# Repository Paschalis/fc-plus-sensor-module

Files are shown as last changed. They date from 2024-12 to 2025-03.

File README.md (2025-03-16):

# FC Plus Sensor Module
<p align="center">
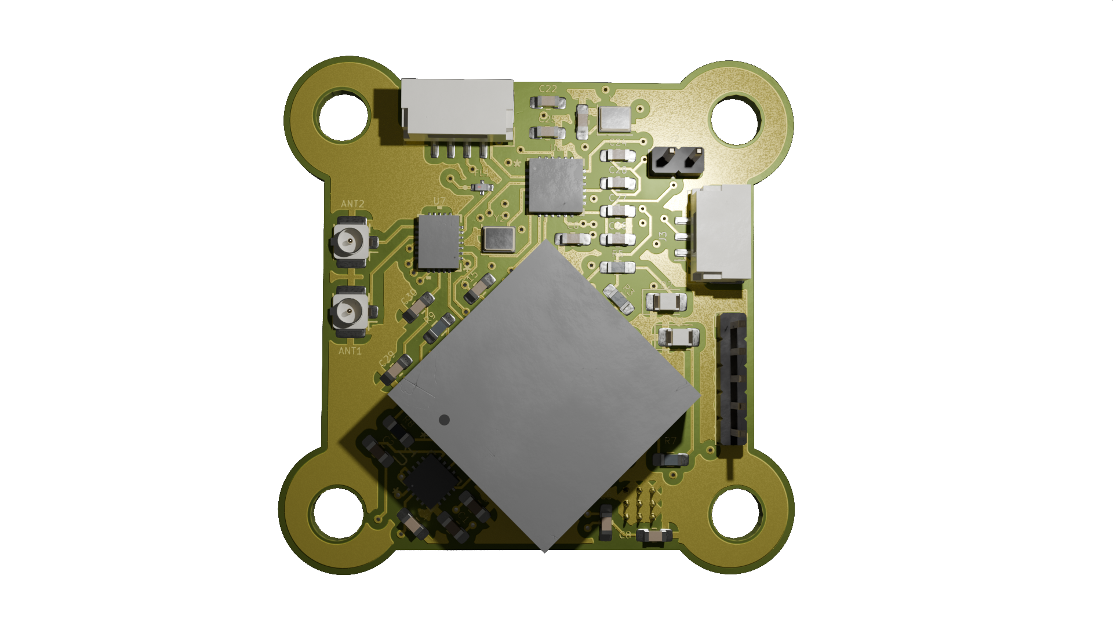
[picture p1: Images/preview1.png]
preview1
  
</p>
<p align="center">
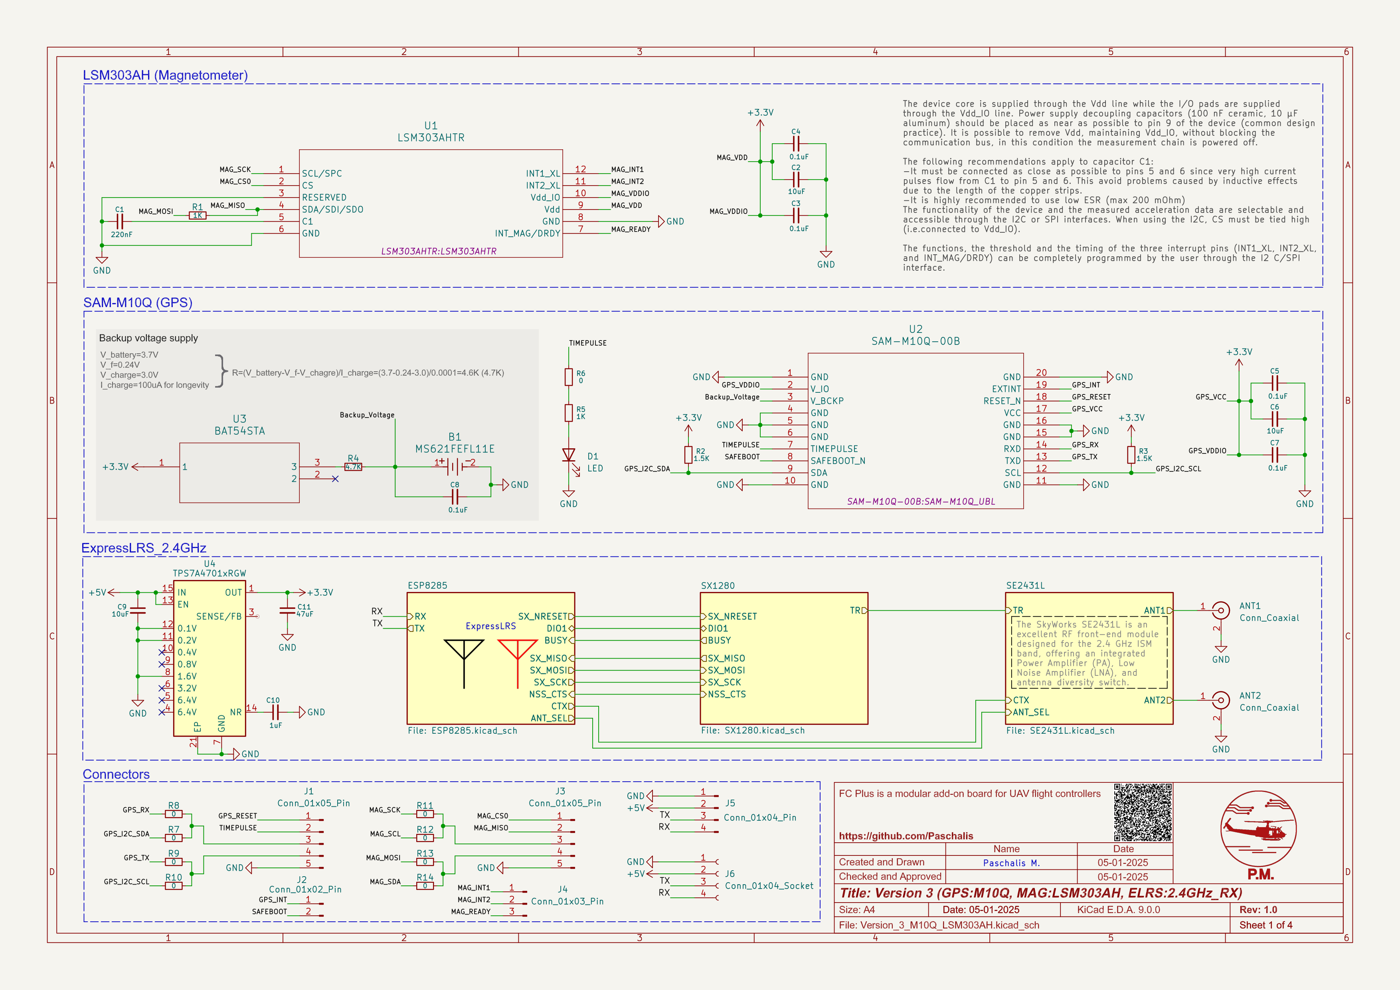
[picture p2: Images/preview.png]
preview
  
</p>

**FC Plus** is a modular add-on board designed for UAV flight controllers, providing advanced telemetry, GPS, object avoidance (ToF, Sonar, IR), and LED indicators for status feedback. This repository contains the necessary documentation, hardware setup guides, sensor integration instructions, and communication protocols (LoRa/WiFi) to enhance UAV autonomy and safety.

# Board Designs Overview

This repository contains a collection of **FC Plus Sensor Modules Boards** categorized by their transmission modes. More details about the transmission modes can be found in the [Transmission Modes Classification](SensorFCPlus/README.md).

> **Note:** The PCB colors are used to visually distinguish the boards. The **Antenna Diversity** boards feature **yellow** PCBs, while the **True Diversity** boards are **blue**. The **Gemini Mode** boards are marked with **red** PCBs, and the **Gemini Xrossband (GemX)** boards are designed with **purple** PCBs for easy identification.

<p align="center">
    <a href="https://paschalis.github.io/fc-plus-sensor-module/" target="_blank">
        
    </a>
</p>

## 1. Antenna Diversity Boards (Yellow Boards)

### FC Plus Sensor Modules Boards at 2.4GHz

| Name | Features | Preview |
|---|---|---|
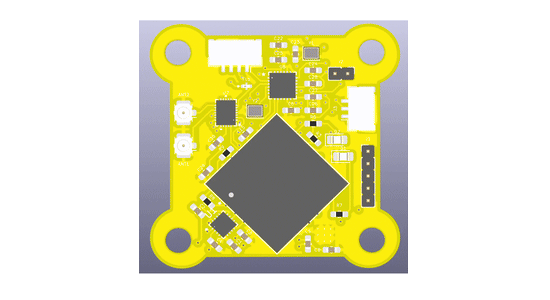
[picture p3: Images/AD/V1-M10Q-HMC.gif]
| V1-M10Q-HMC | GPS: SAM-M10Q, MAG: HMC5883L, ELRS: 2.4GHz RX |  <p align="center"> Click on the image to view the files </p>|
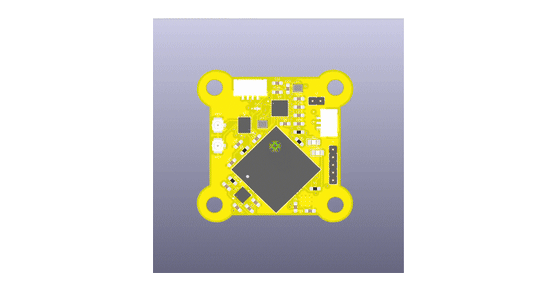
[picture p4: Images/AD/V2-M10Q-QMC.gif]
| V2-M10Q-QMC | GPS: SAM-M10Q, MAG: QMC5883L, ELRS: 2.4GHz RX |  <p align="center"> Click on the image to view the files </p>|
| V3-M10Q-LSM | GPS: SAM-M10Q, MAG: LSM303AH, ELRS: 2.4GHz RX | Preview <p align="center"> Click on the image to view the files </p> |

### FC Plus Sensor Modules Boards at 900MHz

<details>
<summary>Click to view Antenna Diversity Boards at 900MHz</summary>

| Name | Features | Preview |
|---|---|---|
| V1-M10Q-HMC | GPS: SAM-M10Q, MAG: HMC5883L, ELRS: 900MHz RX |  |
| V2-M10Q-QMC | GPS: SAM-M10Q, MAG: QMC5883L, ELRS: 900MHz RX |  |
| V3-M10Q-LSM | GPS: SAM-M10Q, MAG: LSM303AH, ELRS: 900MHz RX |  |

</details>

---
> **Note:** In the following boards, the **LSM303AH** magnetometer was selected over other options due to its **better overall performance**, offering improved accuracy and reliability in magnetic field sensing. The **MAX-M10S** GPS module was chosen instead of the SAM-M10Q for its **lower cost** while still providing good performance for navigation, making it a more economical choice for the boards.

## 2. True Diversity Boards (Blue Boards)

### FC Plus Sensor Modules Boards at 2.4GHz
| Name | Features | Preview |
|---|---|---|
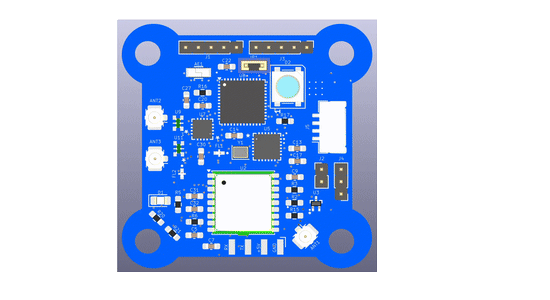
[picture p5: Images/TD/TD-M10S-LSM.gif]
| TD-M10S-LSM | GPS: MAX-M10S, MAG: LSM303AH, ELRS: 2.4GHz RX |  <p align="center"> Click on the image to view the files </p>|

### FC Plus Sensor Modules Boards at 900MHz
<details>
<summary>Click to view True Diversity Boards at 900MHz</summary>

| Name | Features | Preview |
|---|---|---|
| TD-M10S-LSM | GPS: MAX-M10S, MAG: LSM303AH, ELRS: 900MHz RX |  |

</details>

## 3. Gemini Mode Boards

> **Note:**  
> - The **Gemini boards** are actually the **True Diversity boards** operating in **Gemini Mode**.  
> - To enable **Gemini Mode**, set the **RX Antenna Mode** to **Gemini** via Lua script.  
> - **Single Antenna RX boards** can also operate in Gemini Mode but must use **Model 5** in **Model Config Matching** via Lua script.  
> - **Gemini-capable receivers** should use **Model 6** in **Model Config Matching**.  
> - Click on [🔗 **Go to True Diversity Full Diversity Boards (Blue Boards)**](#2-true-diversity-boards-blue-boards) to view compatible receivers.  
>  
> 📖 **Reference:** [ExpressLRS Gemini Mode Documentation](https://www.expresslrs.org/software/gemini/#what-is-gemini)  

## 4. Gemini Xrossband (GemX) Boards (Purple Boards)

### FC Plus Sensor Modules Boards
| Name | Features | Preview |
|---|---|---|
| GemX-M10S-LSM | GPS: MAX-M10S, MAG: LSM303AH, ELRS: 2.4GHz and 900MHz RX |  |

## Related Projects

### **Autonomous UAVs: MAVLink Communication Between FCs and SBCs**
This repository explores MAVLink communication between flight controllers and SBCs, enabling UAV autonomy with features like peripheral integration and real-time image processing.

<div align="center">

             
  

</div>

Explore more about the **MAVLink Communication Between FCs and SBCs** project and its integration into autonomous UAVs by clicking on the badge above to access the full documentation and setup guide.

### **Custom RX/TX Board Designs for GCS Communication**


This repository provides a receiver and transmitter solution for Ground Control Stations (GCS), designed to provide reliable telemetry and control using ELRS, mLRS, and MAVLink protocols. Featuring board designs optimized for long-range communication, minimal latency, and robust performance under varying conditions, these boards cater to diverse operational needs for UAV telemetry systems.

<div align="center">

                              
  

</div>

Explore the **Custom RX/TX Board Designs for GCS Communication** project and its integration into UAV telemetry systems by clicking on the badge above.

## Contributing

Your contributions and suggestions are crucial for the improvement of this project!  Feel free to submit pull requests or open issues if you encounter any problems.

## License

This project is licensed under the [GPLv3 License](https://opensource.org/licenses/GPL-3.0) - see the [LICENSE](LICENSE) file for details.

---

**Thank you for visiting fc-plus-sensor-module!**

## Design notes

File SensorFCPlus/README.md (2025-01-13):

# Transmission Modes Classification

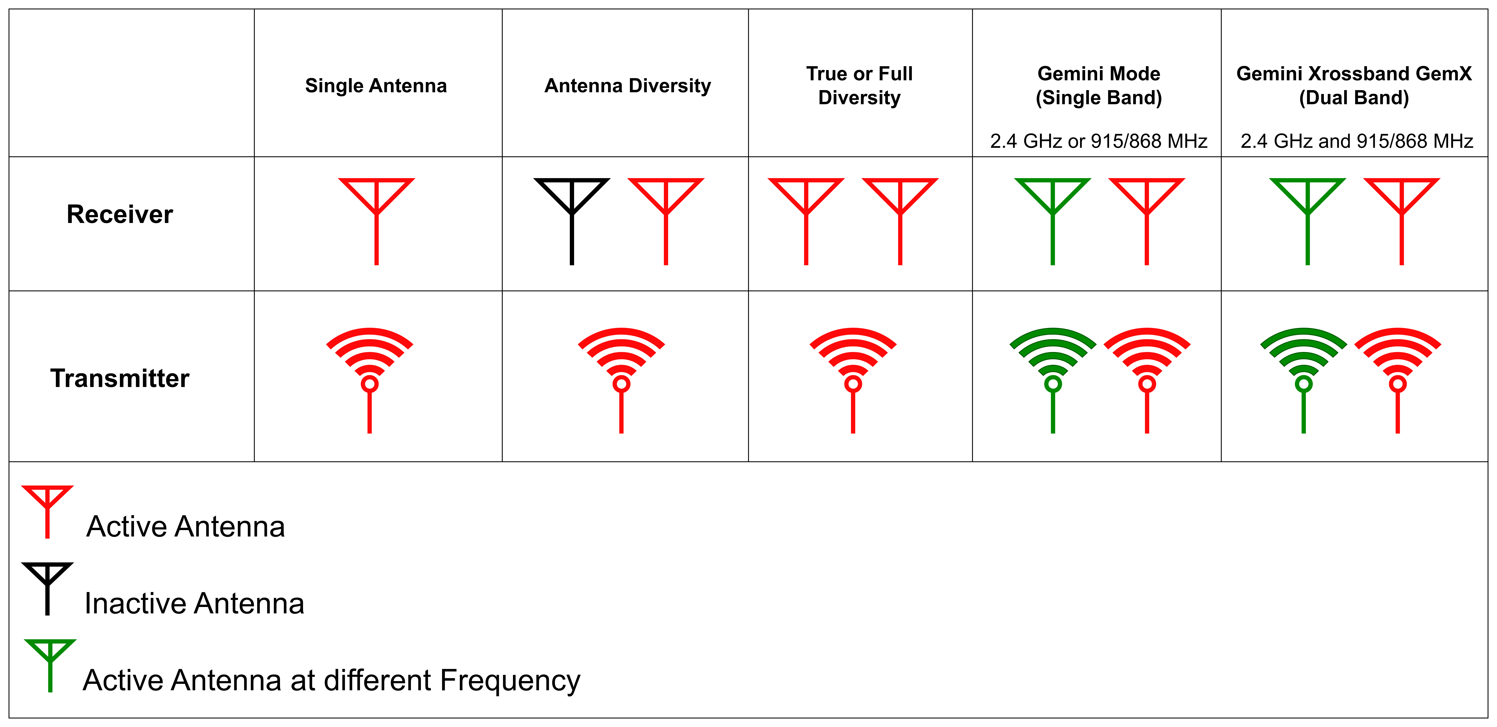
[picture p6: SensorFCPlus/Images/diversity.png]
Gemini Info


This document describes various transmission modes used in long-range LoRa (Long Range) wireless communication for drones. These modes leverage LoRa's unique capabilities to improve Signal Quality (LQ), mitigate interference, and enhance reliability over extended distances, making them ideal for drone applications in diverse environments.
## Transmission Modes

### 1. Single Antenna
- **Description**:  
  Uses one antenna on both the transmitter and receiver, operating over a single frequency channel.
- **Advantages**:  
  - Simplicity  
  - Low cost  
- **Limitations**:  
  - Highly susceptible to interference and signal loss.  

### 2. Antenna Diversity

- **Description**:  
  The receiver employs two antennas to select the best signal, while the transmitter uses a single antenna. Communication occurs over a single frequency channel.  
- **Advantages**:  
  - Improved signal quality due to antenna selection.  
- **Limitations**:  
  - Only one frequency channel is used.  
  - Transmission lacks diversity.  

### 3. True Diversity or Full Diversity
- **Description**:  
  Both the transmitter and receiver utilize two independent Semtech LoRa chips, each connected to its own antenna, operating on the same frequency. This setup provides full diversity for both transmitting and receiving.  
- **Advantages**:  
  - Enhanced signal quality through full transmitter and receiver diversity.  
  - Redundancy in signal transmission and reception.  
- **Limitations**:  
  - Increased complexity and cost.  

### 4. Gemini Mode (Single Band)
- **Description**:  
  The transmitter sends packets on two frequencies within the same band (e.g., 2.4 GHz or 900 MHz), spaced approximately 40 MHz apart for 2.4 GHz and 10 MHz apart for 900 MHz. A true diversity receiver with two antennas and LoRa chips receives both signals simultaneously.  
- **Advantages**:  
  - Superior interference mitigation by utilizing two frequencies within the same band.  
  - Improved stability and reliability of signal quality.  
- **Limitations**:  
  - Limited to a single frequency band.  

### 5. Gemini Xrossband GemX (Dual Band)
- **Description**:  
  The transmitter operates simultaneously on two different frequency bands (e.g., 2.4 GHz and 900 MHz), each managed by independent LoRa chips. The receiver employs true diversity hardware with two antennas and LoRa chips operating on distinct bands.  
- **Advantages**:  
  - Enhanced interference avoidance by operating across separate bands.  
  - Increased performance and redundancy for long-range communication.  
- **Limitations**:  
  - More complex and expensive hardware due to dual-band operation.  

---

## Transmission Mode Classification Chart

| Mode | Frequency Channels | Antennas (TX) | Antennas (RX)| Interference Mitigation | Signal Quality  | Receiver Type |
|---|---|---|---|---|---|---|
| **Single Antenna** | 1 | 1 | 1 | Low | Low | Simple Receiver |
| **Antenna Diversity** | 1 | 1 | 2 | Moderate | Moderate | Diversity Receiver |
| **True Diversity or Full Diversity**  | 1 | 1 | 2 | High | High | Diversity Receiver |
| **Gemini Mode (Single Band)**| 2 (within 1 band) | 2 | 2 | Very High | Very High | Diversity Receiver |
| **Gemini Xrossband GemX (Dual Band)** | 2 (across 2 bands) | 2 | 2 | Excellent | Excellent | Dual-band Receiver |

---

## Summary

This classification illustrates the progression from basic single antenna setups to advanced true diversity and dual-band configurations:

- **Single Antenna** and **Antenna Diversity** provide fundamental solutions suitable for simple environments.  
- **True Diversity** or **Full Diversity** and **Gemini Mode (Single Band)** offer significant enhancements in reliability and interference mitigation within the same band.  
- **Gemini Xrossband GemX (Dual Band)** delivers optimal performance by leveraging dual-band communication, ideal for complex and interference-prone environments.  

Understanding these modes enables the selection of appropriate communication systems tailored to specific drone operation requirements, ensuring robust and efficient wireless links.

---

## References

- [mLRS GitHub Repository](https://github.com/olliw42/mLRS)  
- [mLRS Documentation](https://github.com/olliw42/mLRS-docu)  
- [mLRS Hardware Repository](https://github.com/olliw42/mLRS-hardware/tree/master)  
- [ArduPilot: mLRS RC Overview](https://ardupilot.org/copter/docs/common-mlrs-rc.html)  
- [ExpressLRS: Gemini Overview](https://www.expresslrs.org/software/gemini/)  
- [ExpressLRS Documentation](https://www.expresslrs.org/)  

[⬅️ Go Back to Main README](../README.md)

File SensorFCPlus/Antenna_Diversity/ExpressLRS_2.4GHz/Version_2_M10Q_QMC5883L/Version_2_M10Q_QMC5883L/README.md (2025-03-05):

<div align="center">

# V2-M10Q-QMC

Antenna Diversity 
(GPS: SAM-M10Q, MAG: QMC5883L, ELRS:2.4GHz_RX)

</div>

Board Preview
## Bill of Materials

| Reference | Value | Datasheet | Footprint | Qty | DNP |
|---|---|---|---|-----|-----|
| AE1 | Antenna | ~ | RF_Antenna:Texas_SWRA117D_2.4GHz_Right | 1 | |
| ANT1, ANT2 | Conn_Coaxial | ~ | Connector_Coaxial:U.FL_Hirose_U.FL-R-SMT-1_Vertical | 2 | |
| B1 | MS621FEFL11E | MS621FEFL11E | MS621FE-FL11E:MS621FE-FL11E | 1 | |
| C1, C4, C6, C12, C13, C15 | 0.1uF | ~ | Capacitor_SMD:C_0805_2012Metric_Pad1.18x1.45mm_HandSolder | 6 | |
| C2 | 0.22uF | ~ | Capacitor_SMD:C_0805_2012Metric_Pad1.18x1.45mm_HandSolder | 1 | |
| C3 | 4.7uF | ~ | Capacitor_SMD:C_0805_2012Metric_Pad1.18x1.45mm_HandSolder | 1 | |
| C5, C7, C14, C21 | 10uF | ~ | Capacitor_SMD:C_0805_2012Metric_Pad1.18x1.45mm_HandSolder, ECASD40J106M055K00:ECASD40J106M055K00 | 4 | |
| C8 | 1uF | ~ | Capacitor_SMD:C_0805_2012Metric_Pad1.18x1.45mm_HandSolder | 1 | |
| C9 | 47uF | ~ | Capacitor_SMD:C_0805_2012Metric_Pad1.18x1.45mm_HandSolder | 1 | |
| C10, C11, C16, C17, C18, C19, C20, C24, C28, C32 | 100nF | ~ | Capacitor_SMD:C_0805_2012Metric_Pad1.18x1.45mm_HandSolder | 10  | |
| C22, C23, C30, C31 | 10pF | ~ | Capacitor_SMD:C_0805_2012Metric_Pad1.18x1.45mm_HandSolder | 4 | |
| C25, C26 | 10nF | ~ | Capacitor_SMD:C_0805_2012Metric_Pad1.18x1.45mm_HandSolder | 2 | |
| C27 | 470nF | ~ | Capacitor_SMD:C_0805_2012Metric_Pad1.18x1.45mm_HandSolder | 1 | |
| C29 | 2.2uF | ~ | Capacitor_SMD:C_0805_2012Metric_Pad1.18x1.45mm_HandSolder | 1 | |
| D1, D2 | LED | ~ | LED_SMD:LED_0805_2012Metric_Pad1.15x1.40mm_HandSolder | 2 | |
| FL1 | 2450FM07D0034T | [Datasheet](https://www.mouser.co.uk/datasheet/2/611/2450FM07D0034-1375634.pdf) | 2450FM07D0034T:2450FM07D0034T | 1 | |
| J1 | Conn_01x05_Pin | ~ | Connector_PinHeader_2.00mm:PinHeader_1x05_P2.00mm_Vertical | 1 | |
| J2 | Conn_01x02_Pin | ~ | Connector_PinHeader_2.00mm:PinHeader_1x02_P2.00mm_Vertical | 1 | |
| J3 | Conn_01x03_Socket | ~ | Connector_JST:JST_GH_SM03B-GHS-TB_1x03-1MP_P1.25mm_Horizontal | 1 | |
| J5 | Conn_01x04_Pin | ~ | Connector_JST:JST_GH_SM04B-GHS-TB_1x04-1MP_P1.25mm_Horizontal | 1 | |
| J6 | Conn_01x04_Socket | ~ | Connector_Harwin:Harwin_M20-89004xx_1x04_P2.54mm_Horizontal | 1 | |
| JP1 | Jumper_2_Bridged | ~ | Jumper:SolderJumper-2_P1.3mm_Open_RoundedPad1.0x1.5mm | 1 | |
| R1, R2, R8, R9 | 1.5K | ~ | Resistor_SMD:R_0805_2012Metric_Pad1.20x1.40mm_HandSolder | 4 | |
| R3, R6, R18, R19, R20, R21, R23, R25 | 0 | ~ | Resistor_SMD:R_0603_1608Metric_Pad0.98x0.95mm_HandSolder, Resistor_SMD:R_0805_2012Metric_Pad1.20x1.40mm_HandSolder | 8 | |
| R4 | 4.7K | ~ | Resistor_SMD:R_0805_2012Metric_Pad1.20x1.40mm_HandSolder | 1 | |
| R5, R7 | 1K | ~ | Resistor_SMD:R_0805_2012Metric_Pad1.20x1.40mm_HandSolder | 2 | |
| R10, R11, R12, R13, R17 | 10K | ~ | Resistor_SMD:R_0805_2012Metric_Pad1.20x1.40mm_HandSolder | 5 | |
| R14 | 12K | ~ | Resistor_SMD:R_0805_2012Metric_Pad1.20x1.40mm_HandSolder | 1 | |
| R15 | 2.2K | ~ | Resistor_SMD:R_0805_2012Metric_Pad1.20x1.40mm_HandSolder | 1 | |
| R16 | 1.2K | ~ | Resistor_SMD:R_0805_2012Metric_Pad1.20x1.40mm_HandSolder | 1 | |
| U1 | QMC5883L | QMC5883L | QMC5883L:QMC5883L_QST | 1 | |
| U2 | SAM-M10Q-00B | SAM-M10Q-00B | SAM-M10Q-00B:SAM-M10Q_UBL | 1 | |
| U3 | BAT54STA | BAT54STA | BAT54STA:BAT54STA | 1 | |
| U4 | TPS7A4701xRGW | [Datasheet](https://www.ti.com/lit/ds/symlink/tps7a47.pdf) | Package_DFN_QFN:Texas_RGW0020A_VQFN-20-1EP_5x5mm_P0.65mm_EP3.15x3.15mm_ThermalVias | 1 | |
| U5 | ESP8285H16 | ESP8285H16 | ESP8285H16:QFN32_5X5_EXP | 1 | |
| U6 | SX1280IMLTRT | SX1280IMLTRT | SX1280IMLTRT:QFN24_4X4_SEM | 1 | |
| U7 | SE2431L-R | SE2431L-R | SE2431L-R:SE2431L_SKY | 1 | |
| Y1 | 26MHz | ~ | Crystal:Crystal_SMD_2016-4Pin_2.0x1.6mm | 1 | |
| Y2 | 52MHz | ~ | Crystal:Crystal_SMD_2016-4Pin_2.0x1.6mm | 1 | |

[⬅️ Go Back to Main README](https://github.com/Paschalis/fc-plus-sensor-module)

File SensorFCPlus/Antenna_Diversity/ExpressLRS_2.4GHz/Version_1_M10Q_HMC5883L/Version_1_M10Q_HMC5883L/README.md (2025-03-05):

<div align="center">

# V1-M10Q-HMC

Antenna Diversity 
(GPS: SAM-M10Q, MAG: HMC5883L, ELRS:2.4GHz_RX)

</div>

Board Preview
## Bill of Materials

| Reference | Value | Datasheet | Footprint | Qty | DNP |
|---|---|---|---|-----|-----|
| AE1 | Antenna | N/A | RF_Antenna:Texas_SWRA117D_2.4GHz_Right | 1 | |
| ANT1, ANT2 | Conn_Coaxial | N/A | Connector_Coaxial:U.FL_Hirose_U.FL-R-SMT-1_Vertical | 2 | |
| B1 | MS621FEFL11E | [Datasheet](MS621FEFL11E) | MS621FE-FL11E:MS621FE-FL11E | 1 | |
| C1, C4, C6... | 0.1uF | N/A | Capacitor_SMD:C_0805_2012Metric_Pad1.18x1.45mm_HandSolder | 6 | |
| C2 | 0.22uF | N/A | Capacitor_SMD:C_0805_2012Metric_Pad1.18x1.45mm_HandSolder | 1 | |
| C3 | 4.7uF | N/A | Capacitor_SMD:C_0805_2012Metric_Pad1.18x1.45mm_HandSolder | 1 | |
| C5, C7, C14, C21 | 10uF | N/A | Capacitor_SMD:C_0805_2012Metric_Pad1.18x1.45mm_HandSolder, ECASD40J106M055K00:ECASD40J106M055K00 | 4 | |
| C8 | 1uF | N/A | Capacitor_SMD:C_0805_2012Metric_Pad1.18x1.45mm_HandSolder | 1 | |
| C9 | 47uF | N/A | Capacitor_SMD:C_0805_2012Metric_Pad1.18x1.45mm_HandSolder | 1 | |
| C10, C11, C16... | 100nF | N/A | Capacitor_SMD:C_0805_2012Metric_Pad1.18x1.45mm_HandSolder | 10  | |
| C22, C23, C30, C31 | 10pF | N/A | Capacitor_SMD:C_0805_2012Metric_Pad1.18x1.45mm_HandSolder | 4 | |
| C25, C26 | 10nF | N/A | Capacitor_SMD:C_0805_2012Metric_Pad1.18x1.45mm_HandSolder | 2 | |
| C27 | 470nF | N/A | Capacitor_SMD:C_0805_2012Metric_Pad1.18x1.45mm_HandSolder | 1 | |
| C29 | 2.2uF | N/A | Capacitor_SMD:C_0805_2012Metric_Pad1.18x1.45mm_HandSolder | 1 | |
| D1, D2 | LED | N/A | LED_SMD:LED_0805_2012Metric_Pad1.15x1.40mm_HandSolder | 2 | |
| FL1 | 2450FM07D0034T | [Datasheet](https://www.mouser.co.uk/datasheet/2/611/2450FM07D0034-1375634.pdf) | 2450FM07D0034T:2450FM07D0034T | 1 | |
| J1 | Conn_01x05_Pin | N/A | Connector_PinHeader_2.00mm:PinHeader_1x05_P2.00mm_Vertical | 1 | |
| J2 | Conn_01x02_Pin | N/A | Connector_PinHeader_2.00mm:PinHeader_1x02_P2.00mm_Vertical | 1 | |
| J3 | Conn_01x03_Socket | N/A | Connector_JST:JST_GH_SM03B-GHS-TB_1x03-1MP_P1.25mm_Horizontal | 1 | |
| J5 | Conn_01x04_Pin | N/A | Connector_JST:JST_GH_SM04B-GHS-TB_1x04-1MP_P1.25mm_Horizontal | 1 | |
| J6 | Conn_01x04_Socket | N/A | Connector_Harwin:Harwin_M20-89004xx_1x04_P2.54mm_Horizontal | 1 | |
| JP1 | Jumper_2_Bridged | N/A | Jumper:SolderJumper-2_P1.3mm_Open_RoundedPad1.0x1.5mm | 1 | |
| R1, R2, R8, R9 | 1.5K | N/A | Resistor_SMD:R_0805_2012Metric_Pad1.20x1.40mm_HandSolder | 4 | |
| R3, R6, R18... | 0 | N/A | Resistor_SMD:R_0603_1608Metric_Pad0.98x0.95mm_HandSolder, Resistor_SMD:R_0805_2012Metric_Pad1.20x1.40mm_HandSolder | 8 | |
| R4 | 4.7K | N/A | Resistor_SMD:R_0805_2012Metric_Pad1.20x1.40mm_HandSolder | 1 | |
| R5, R7 | 1K | N/A | Resistor_SMD:R_0805_2012Metric_Pad1.20x1.40mm_HandSolder | 2 | |
| R10, R11, R12... | 10K | N/A | Resistor_SMD:R_0805_2012Metric_Pad1.20x1.40mm_HandSolder | 5 | |
| R14 | 12K | N/A | Resistor_SMD:R_0805_2012Metric_Pad1.20x1.40mm_HandSolder | 1 | |
| R15 | 2.2K | N/A | Resistor_SMD:R_0805_2012Metric_Pad1.20x1.40mm_HandSolder | 1 | |
| R16 | 1.2K | N/A | Resistor_SMD:R_0805_2012Metric_Pad1.20x1.40mm_HandSolder | 1 | |
| U1 | HMC5883L | [Datasheet](HMC5883L) | HMC5883L:LPCC16_HNW | 1 | |
| U2 | SAM-M10Q-00B | [Datasheet](SAM-M10Q-00B) | SAM-M10Q-00B:SAM-M10Q_UBL | 1 | |
| U3 | BAT54STA | [Datasheet](BAT54STA) | BAT54STA:BAT54STA | 1 | |
| U4 | TPS7A4701xRGW | [Datasheet](https://www.ti.com/lit/ds/symlink/tps7a47.pdf) | Package_DFN_QFN:Texas_RGW0020A_VQFN-20-1EP_5x5mm_P0.65mm_EP3.15x3.15mm_ThermalVias | 1 | |
| U5 | ESP8285H16 | [Datasheet](ESP8285H16) | ESP8285H16:QFN32_5X5_EXP | 1 | |
| U6 | SX1280IMLTRT | [Datasheet](SX1280IMLTRT) | SX1280IMLTRT:QFN24_4X4_SEM | 1 | |
| U7 | SE2431L-R | [Datasheet](SE2431L-R) | SE2431L-R:SE2431L_SKY | 1 | |
| Y1 | 26MHz | N/A | Crystal:Crystal_SMD_2016-4Pin_2.0x1.6mm | 1 | |
| Y2 | 52MHz | N/A | Crystal:Crystal_SMD_2016-4Pin_2.0x1.6mm | 1 | |

[⬅️ Go Back to Main README](https://github.com/Paschalis/fc-plus-sensor-module)

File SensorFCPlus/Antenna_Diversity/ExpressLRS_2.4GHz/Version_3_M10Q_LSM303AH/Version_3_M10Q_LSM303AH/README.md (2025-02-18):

<div align="center">

# V3-M10Q-LSM

Antenna Diversity 
(GPS: SAM-M10Q, MAG: LSM303AH, ELRS:2.4GHz_RX)

</div>

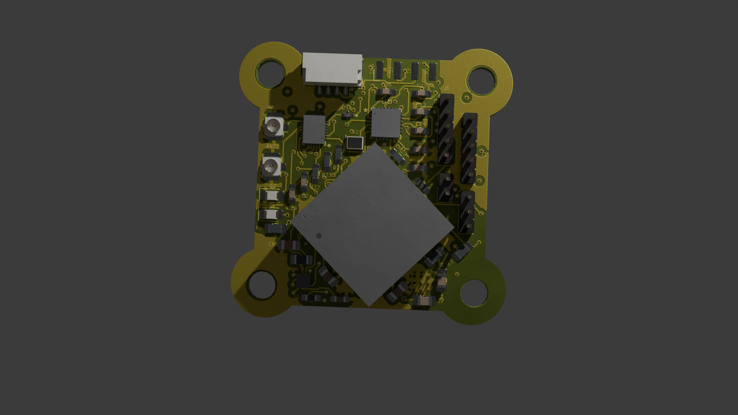
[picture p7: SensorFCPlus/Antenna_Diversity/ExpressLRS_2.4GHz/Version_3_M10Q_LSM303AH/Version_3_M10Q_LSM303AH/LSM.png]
Board Preview

## Bill of Materials

| **Reference** | **Value** | **Datasheet** | **Footprint** | **Qty** | **DNP** |
|---|---|---|---|---|---|
| **AE1** | Antenna | ~ | RF_Antenna:Texas_SWRA117D_2.4GHz_Right | 1 | |
| **ANT1, ANT2**  | Conn_Coaxial | ~ | Connector_Coaxial:U.FL_Hirose_U.FL-R-SMT-1_Vertical | 2 | |
| **B1** | MS621FEFL11E | MS621FEFL11E  | MS621FE-FL11E:MS621FE-FL11E | 1 | |
| **C1** | 220nF | ~ | Capacitor_SMD:C_0603_1608Metric_Pad1.08x0.95mm_HandSolder| 1 | |
| **C2, C6, C9, C13, C21** | 10uF | ~ | -- mixed values -- | 5 | |
| **C3, C4, C5, C7, C8, C12** | 0.1uF | ~ | -- mixed values -- | 6 | |
| **C10** | 1uF | ~ | Capacitor_SMD:C_0805_2012Metric_Pad1.18x1.45mm_HandSolder| 1 | |
| **C11** | 47uF | ~ | Capacitor_SMD:C_0805_2012Metric_Pad1.18x1.45mm_HandSolder| 1 | |
| **C14–C20, C24, C28, C31** | 100nF | ~ | -- mixed values -- | 10 | |
| **C22, C23, C29, C30** | 10pF | ~ | -- mixed values -- | 4 | |
| **C25, C26** | 10nF | ~ | Capacitor_SMD:C_0603_1608Metric_Pad1.08x0.95mm_HandSolder| 2 | |
| **C27** | 470nF | ~ | Capacitor_SMD:C_0603_1608Metric_Pad1.08x0.95mm_HandSolder| 1 | |
| **C32** | 2.2uF | ~ | Capacitor_SMD:C_0603_1608Metric_Pad1.08x0.95mm_HandSolder| 1 | |
| **D1, D2** | LED | ~ | LED_SMD:LED_0805_2012Metric_Pad1.15x1.40mm_HandSolder | 2 | |
| **FL1** | 2450FM07D0034T | [Datasheet](https://www.mouser.co.uk/datasheet/2/611/2450FM07D0034-1375634.pdf) | 2450FM07D0034T:2450FM07D0034T | 1 | |
| **J1, J3** | Conn_01x05_Pin | ~ | Connector_PinHeader_2.00mm:PinHeader_1x05_P2.00mm_Vertical| 2 | |
| **J2** | Conn_01x02_Pin | ~ | Connector_PinHeader_2.00mm:PinHeader_1x02_P2.00mm_Vertical| 1 | |
| **J4** | Conn_01x03_Pin | ~ | Connector_PinHeader_2.00mm:PinHeader_1x03_P2.00mm_Vertical| 1 | |
| **J5** | Conn_01x04_Pin | ~ | Connector_JST:JST_GH_SM04B-GHS-TB_1x04-1MP_P1.25mm_Horizontal| 1 | |
| **J6** | Conn_01x04_Socket | ~ | Connector_Harwin:Harwin_M20-89004xx_1x04_P2.54mm_Horizontal| 1 | |
| **JP1** | Jumper_2_Bridged  | ~ | Jumper:SolderJumper-2_P1.3mm_Open_RoundedPad1.0x1.5mm | 1 | |
| **R1, R5, R16** | 1K | ~ | -- mixed values -- | 3 | |
| **R2, R3** | 1.5K | ~ | Resistor_SMD:R_0805_2012Metric_Pad1.20x1.40mm_HandSolder | 2 | |
| **R4** | 4.7K | ~ | Resistor_SMD:R_0805_2012Metric_Pad1.20x1.40mm_HandSolder | 1 | |
| **R6–R15** | 0 | ~ | -- mixed values -- | 10 | |
| **R17–R20, R22**| 10K | ~ | -- mixed values -- | 5 | |
| **R21** | 12K | ~ | Resistor_SMD:R_0603_1608Metric_Pad0.98x0.95mm_HandSolder | 1 | |
| **R23** | 2.2K | ~ | Resistor_SMD:R_0603_1608Metric_Pad0.98x0.95mm_HandSolder | 1 | |
| **R24** | 1.2K | ~ | Resistor_SMD:R_0603_1608Metric_Pad0.98x0.95mm_HandSolder | 1 | |
| **U1** | LSM303AHTR | LSM303AHTR | LSM303AHTR:LSM303AHTR | 1 | |
| **U2** | SAM-M10Q-00B | SAM-M10Q-00B  | SAM-M10Q-00B:SAM-M10Q_UBL | 1 | |
| **U3** | BAT54STA | BAT54STA | SOT23_BAT54STA_1P7XP85_DIO | 1 | |
| **U4** | TPS7A4701xRGW | [Datasheet](https://www.ti.com/lit/ds/symlink/tps7a47.pdf) | Package_DFN_QFN:Texas_RGW0020A_VQFN-20-1EP_5x5mm | 1  | |
| **U5** | ESP8285H16 | ESP8285H16 | ESP8285H16:QFN32_5X5_EXP | 1 | |
| **U6** | SX1280IMLTRT | SX1280IMLTRT  | SX1280IMLTRT:QFN24_4X4_SEM | 1 | |
| **U7** | SE2431L-R | SE2431L-R | SE2431L-R:SE2431L_SKY | 1 | |
| **Y1** | 26MHz | ~ | Crystal:Crystal_SMD_2016-4Pin_2.0x1.6mm | 1 | |
| **Y2** | 52MHz | ~ | Crystal:Crystal_SMD_2016-4Pin_2.0x1.6mm | 1 | |

[⬅️ Go Back to Main README](https://github.com/Paschalis/fc-plus-sensor-module)

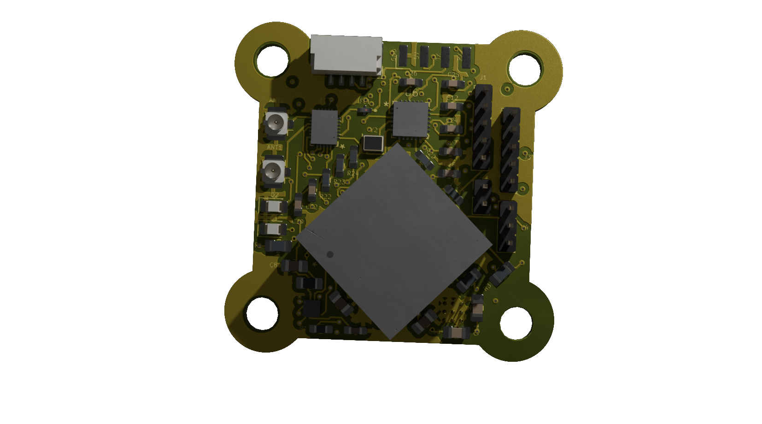
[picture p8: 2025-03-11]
docs/Images/LSM.png

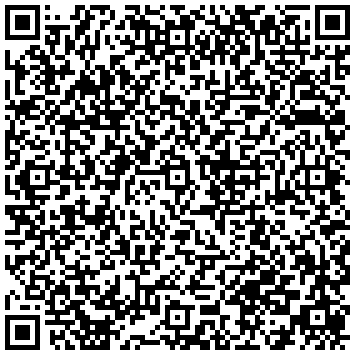
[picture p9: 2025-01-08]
Images/QR/Version 3 (GPS:M10Q, MAG:LSM303AH, ELRS:900MHz_RX).png

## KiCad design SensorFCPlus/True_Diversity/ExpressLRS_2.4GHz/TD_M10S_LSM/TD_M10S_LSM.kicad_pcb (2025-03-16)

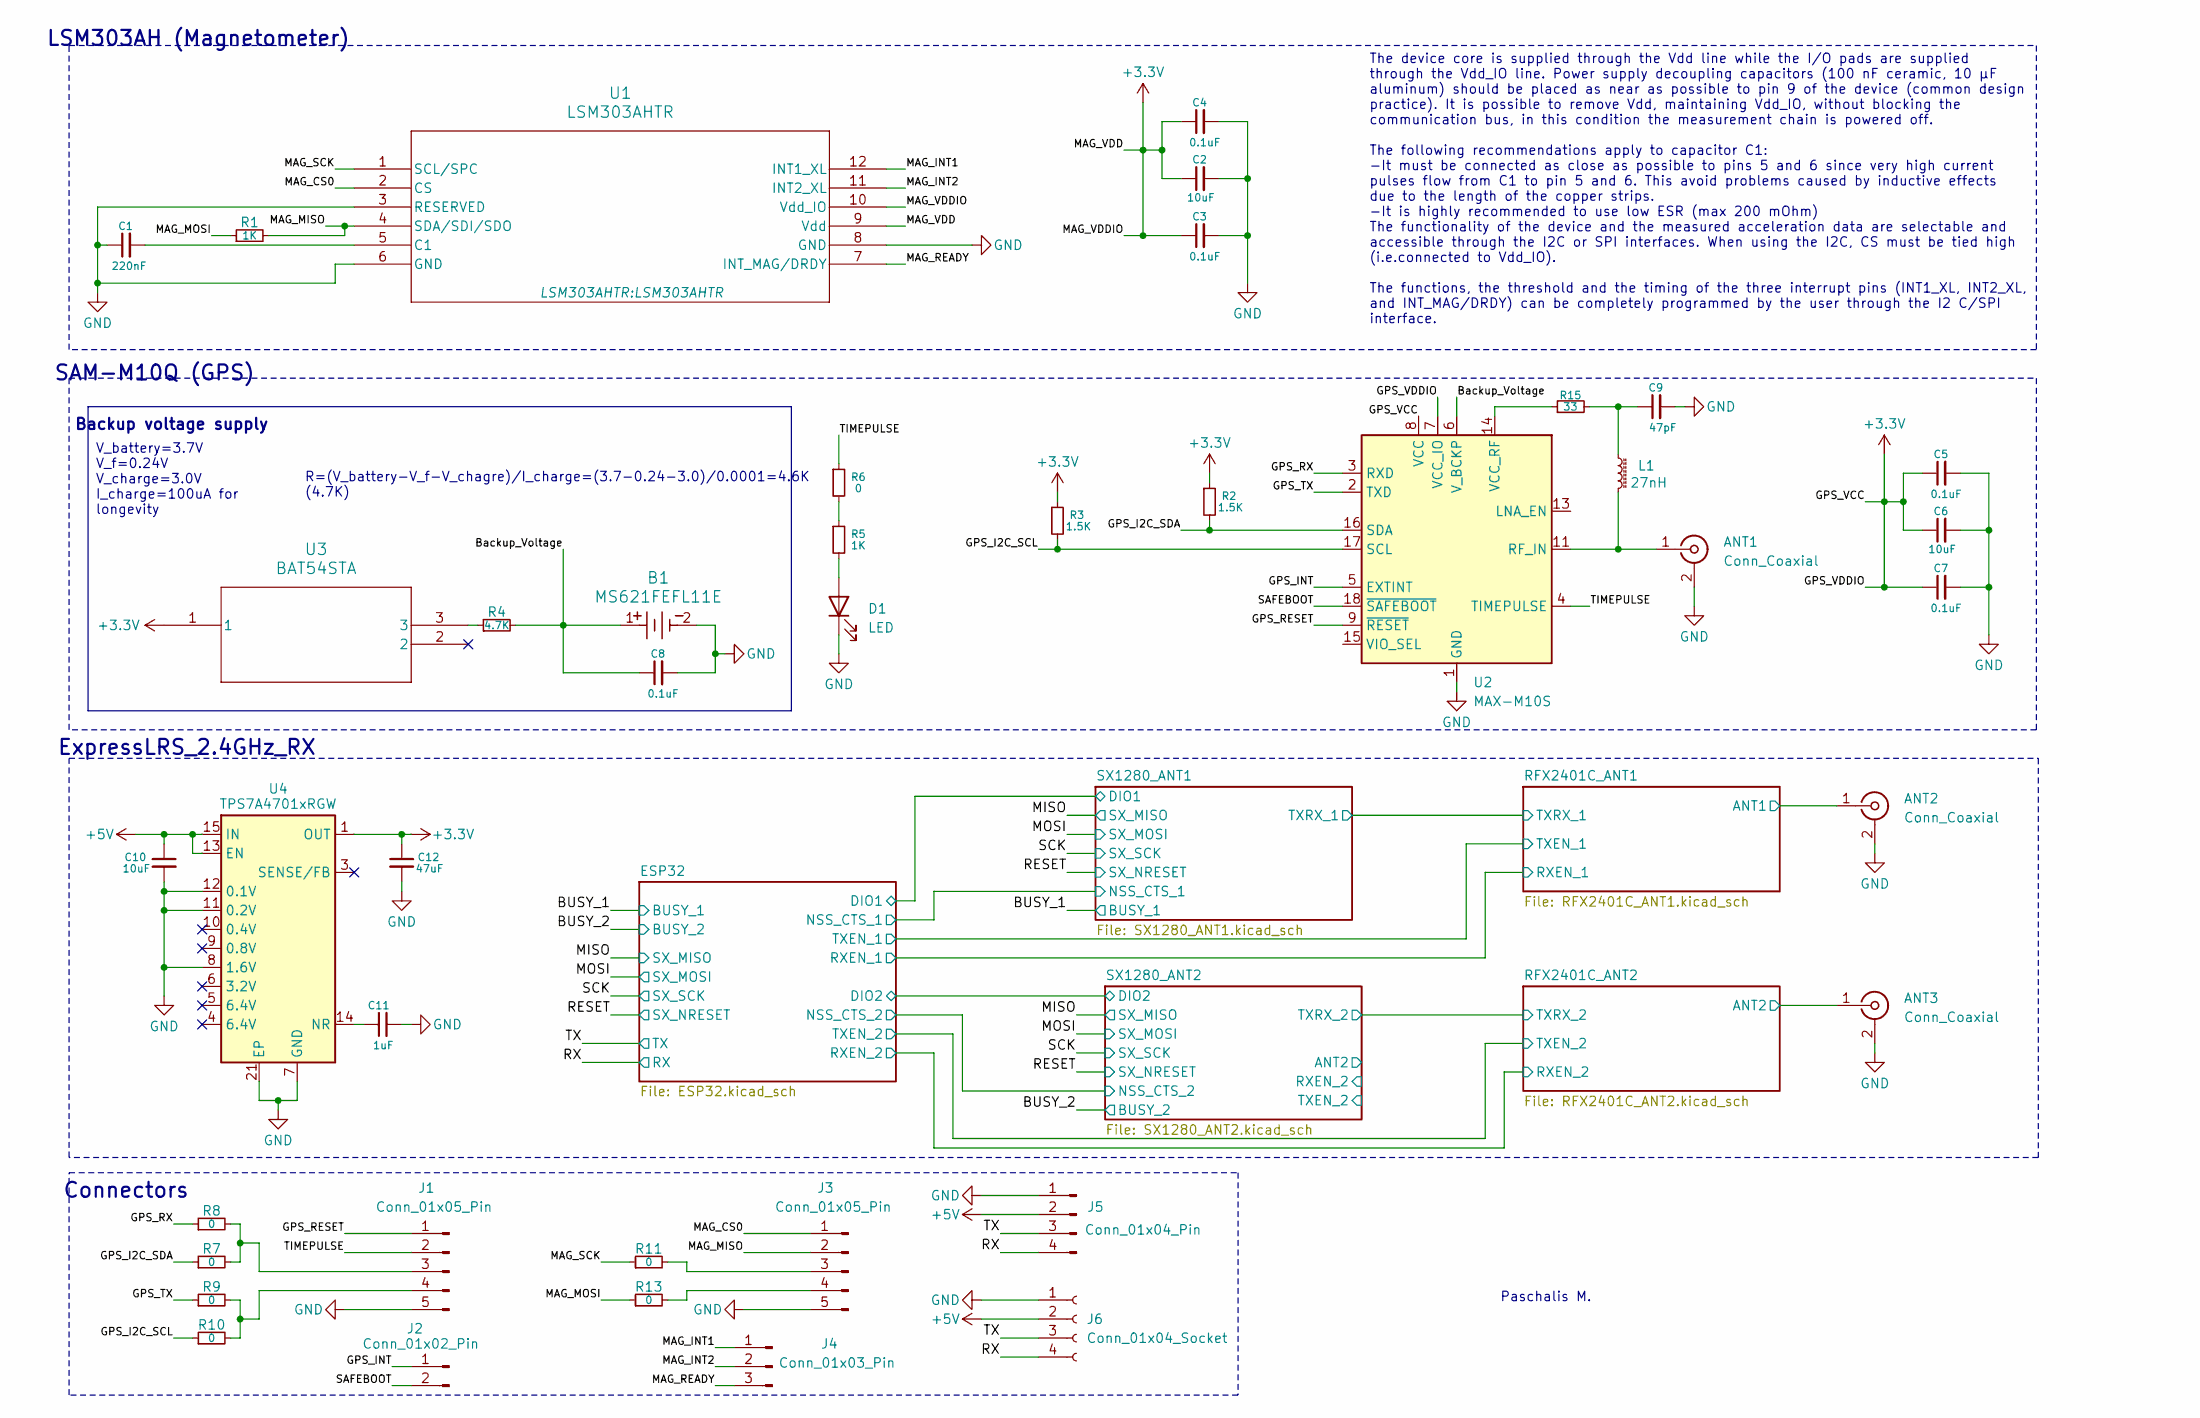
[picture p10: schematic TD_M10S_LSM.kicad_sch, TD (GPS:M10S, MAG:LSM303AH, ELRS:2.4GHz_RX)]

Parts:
ANT1, ANT2, ANT3: Conn_Coaxial; U.FL_Hirose_U.FL-R-SMT-1_Vertical
B1: MS621FEFL11E; MS621FE-FL11E
C1: 220nF; C_0603_1608Metric_Pad1.08x0.95mm_HandSolder
C2, C6: 10uF; ECASD40J106M055K00
C3, C4, C5, C7, C8: 0.1uF; C_0603_1608Metric_Pad1.08x0.95mm_HandSolder
C9: 47pF; C_0603_1608Metric_Pad1.08x0.95mm_HandSolder
C10: 10uF; C_0603_1608Metric_Pad1.08x0.95mm_HandSolder
C11: 1uF; C_0603_1608Metric_Pad1.08x0.95mm_HandSolder
C12: 47uF; C_0603_1608Metric_Pad1.08x0.95mm_HandSolder
D1: LED; LED_0805_2012Metric_Pad1.15x1.40mm_HandSolder
J1, J3: Conn_01x05_Pin; PinHeader_1x05_P2.00mm_Vertical
J2: Conn_01x02_Pin; PinHeader_1x02_P2.00mm_Vertical
J4: Conn_01x03_Pin; PinHeader_1x03_P2.00mm_Vertical
J5: Conn_01x04_Pin; JST_GH_SM04B-GHS-TB_1x04-1MP_P1.25mm_Horizontal
J6: Conn_01x04_Socket; Harwin_M20-89004xx_1x04_P2.54mm_Horizontal
L1: 27nH; L_6.3x6.3_H3
R1, R5: 1K; R_0603_1608Metric_Pad0.98x0.95mm_HandSolder
R2, R3: 1.5K; R_0603_1608Metric_Pad0.98x0.95mm_HandSolder
R4: 4.7K; R_0603_1608Metric_Pad0.98x0.95mm_HandSolder
R6, R7, R8, R9, R10, R11, R13: 0; R_0603_1608Metric_Pad0.98x0.95mm_HandSolder
R15: 33; R_0603_1608Metric_Pad0.98x0.95mm_HandSolder
U1: LSM303AHTR
U2: MAX-M10S; ublox_MAX
U3: BAT54STA
U4: TPS7A4701xRGW; Texas_RGW0020A_VQFN-20-1EP_5x5mm_P0.65mm_EP3.15x3.15mm_Ther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

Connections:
+3.3V: C2.1, C3.1, C4.1, C5.1, C6.1, C7.1, C12.1, R2.1, R3.1, U1.9 (Vdd), U1.10 (Vdd_IO), U2.7 (VCC_IO), U2.8 (VCC), U3.1, U4.1 (OUT), U4.20 (OUT); also elsewhere on the board
+5V: C10.1, J5.2, J6.2, U4.13 (EN), U4.15 (IN), U4.16 (IN); also elsewhere on the board
/Backup_Voltage: B1.1, C8.1, R4.2, U2.6 (V_BCKP)
/GPS_I2C_SCL: R3.2, R10.1, U2.17 (SCL)
/GPS_I2C_SDA: R2.2, R7.1, U2.16 (SDA)
/GPS_INT: J2.1, U2.5 (EXTINT)
/GPS_RESET: J1.1, U2.9 (~RESET)
/GPS_RX: R8.1, U2.3 (RXD)
/GPS_TX: R9.1, U2.2 (TXD)
/MAG_CS0: J3.1, U1.2 (CS)
/MAG_INT1: J4.1, U1.12 (INT1_XL)
/MAG_INT2: J4.2, U1.11 (INT2_XL)
/MAG_MISO: J3.2, R1.2, U1.4 (SDA/SDI/SDO)
/MAG_MOSI: R1.1, R13.1
/MAG_READY: J4.3, U1.7 (INT_MAG/DRDY)
/MAG_SCK: R11.1, U1.1 (SCL/SPC)
/RFX2401C_ANT1/ANT1: ANT2.1 (In); also elsewhere on the board
/RFX2401C_ANT2/ANT2: ANT3.1 (In); also elsewhere on the board
/RX: J5.4, J6.4; also elsewhere on the board
/SAFEBOOT: J2.2, U2.18 (~SAFEBOOT)
/TIMEPULSE: J1.2, R6.1, U2.4 (TIMEPULSE)
/TX: J5.3, J6.3; also elsewhere on the board
GND: ANT1.2 (Ext), ANT2.2 (Ext), ANT3.2 (Ext), B1.2, C1.1, C2.2, C3.2, C4.2, C5.2, C6.2, C7.2, C8.2, C9.2, C10.2, C11.2, C12.2, D1.1 (K), J1.5, J3.5, J5.1, J6.1, U1.3 (RESERVED), U1.6 (GND), U1.8 (GND), U2.1 (GND), U2.10 (GND), U2.12 (GND), U4.7 (GND), U4.8 (1.6V), U4.11 (0.2V), U4.12 (0.1V), U4.21 (EP); also elsewhere on the board
unnamed: ANT1.1 (In), L1.2, U2.11 (RF_IN)
unnamed: C9.1, L1.1, R15.2
unnamed: D1.2 (A), R5.2
unnamed: J1.3, R7.2, R8.2
unnamed: J1.4, R9.2, R10.2
unnamed: J3.3, R11.2
unnamed: J3.4, R13.2
unnamed: R4.1, U3.3
unnamed: R5.1, R6.2
unnamed: C1.2, U1.5 (C1)
unnamed: R15.1, U2.14 (VCC_RF)
unnamed: C11.1, U4.14 (NR)

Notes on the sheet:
Backup voltage supply
Paschalis M.
Connectors
SAM-M10Q (GPS)
LSM303AH (Magnetometer)
ExpressLRS_2.4GHz_RX
The device core is supplied through the Vdd line while the I/O pads are supplied through the Vdd_IO line. Power supply decoupling capacitors (100 nF ceramic, 10 μF aluminum) should be placed as near as possible to pin 9 of the device (common design practice). It is possible to remove Vdd, maintaini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
V_battery=3.7V V_f=0.24V V_charge=3.0V I_charge=100uA for longevity
R=(V_battery-V_f-V_chagre)/I_charge=(3.7-0.24-3.0)/0.0001=4.6K (4.7K)

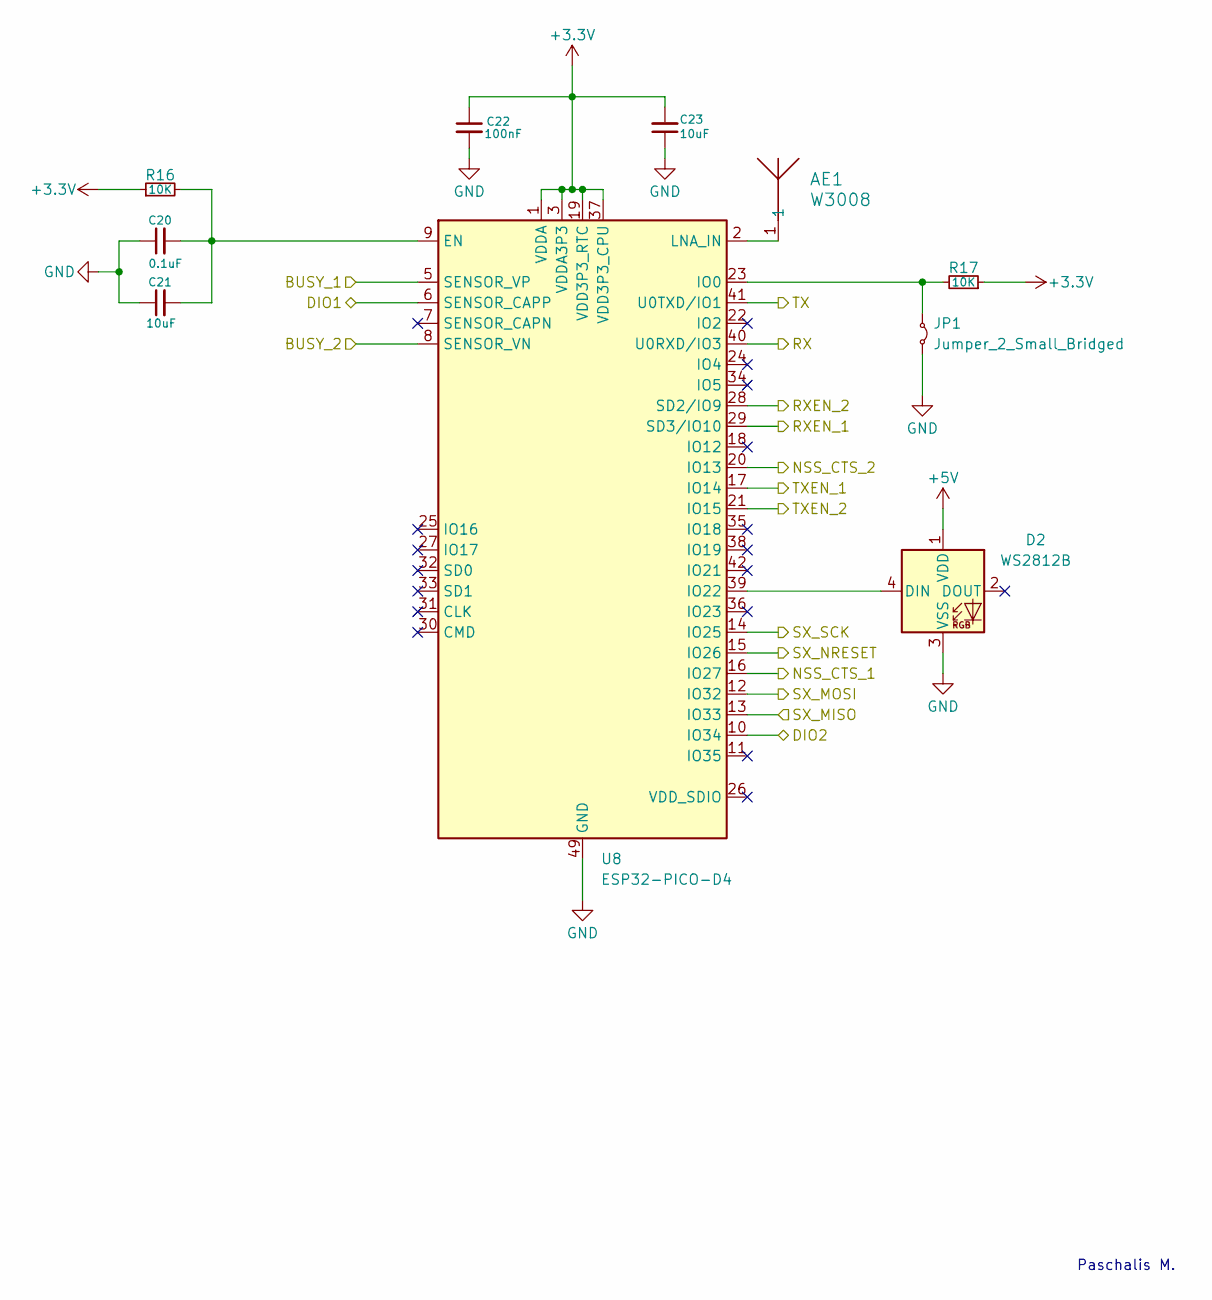
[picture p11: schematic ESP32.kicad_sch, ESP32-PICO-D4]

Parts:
AE1: W3008; ANT_W3008_PUL
C20: 0.1uF; C_0603_1608Metric_Pad1.08x0.95mm_HandSolder
C21, C23: 10uF; ECASD40J106M055K00
C22: 100nF; C_0603_1608Metric_Pad1.08x0.95mm_HandSolder
D2: WS2812B; LED_WS2812B_PLCC4_5.0x5.0mm_P3.2mm
JP1: Jumper_2_Small_Bridged; TestPoint_2Pads_Pitch2.54mm_Drill0.8mm
R16, R17: 10K; R_0603_1608Metric_Pad0.98x0.95mm_HandSolder
U8: ESP32-PICO-D4; QFN-48-1EP_7x7mm_P0.5mm_EP5.1x5.1mm_ThermalVias

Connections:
+3.3V: C22.1, C23.2, R16.1, R17.1, U8.1 (VDDA), U8.3 (VDDA3P3), U8.4 (VDDA3P3), U8.19 (VDD3P3_RTC), U8.37 (VDD3P3_CPU), U8.43 (VDDA), U8.46 (VDDA); also elsewhere on the board
+5V: D2.1 (VDD); also elsewhere on the board
/BUSY_1: U8.5 (SENSOR_VP); also elsewhere on the board
/BUSY_2: U8.8 (SENSOR_VN); also elsewhere on the board
/ESP32/DIO1: U8.6 (SENSOR_CAPP); also elsewhere on the board
/ESP32/DIO2: U8.10 (IO34); also elsewhere on the board
/ESP32/NSS_CTS_1: U8.16 (IO27); also elsewhere on the board
/ESP32/NSS_CTS_2: U8.20 (IO13); also elsewhere on the board
/ESP32/RXEN_1: U8.29 (SD3/IO10); also elsewhere on the board
/ESP32/RXEN_2: U8.28 (SD2/IO9); also elsewhere on the board
/ESP32/TXEN_1: U8.17 (IO14); also elsewhere on the board
/ESP32/TXEN_2: U8.21 (IO15); also elsewhere on the board
/MISO: U8.13 (IO33); also elsewhere on the board
/MOSI: U8.12 (IO32); also elsewhere on the board
/RESET: U8.15 (IO26); also elsewhere on the board
/RX: U8.40 (U0RXD/IO3); also elsewhere on the board
/SCK: U8.14 (IO25); also elsewhere on the board
/TX: U8.41 (U0TXD/IO1); also elsewhere on the board
GND: C20.1, C21.1, C22.2, C23.1, D2.3 (VSS), JP1.2 (B), U8.49 (GND); also elsewhere on the board
unnamed: D2.4 (DIN), U8.39 (IO22)
unnamed: JP1.1 (A), R17.2, U8.23 (IO0)
unnamed: C20.2, C21.2, R16.2, U8.9 (EN)
unnamed: AE1.1, U8.2 (LNA_IN)

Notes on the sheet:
Paschalis M.

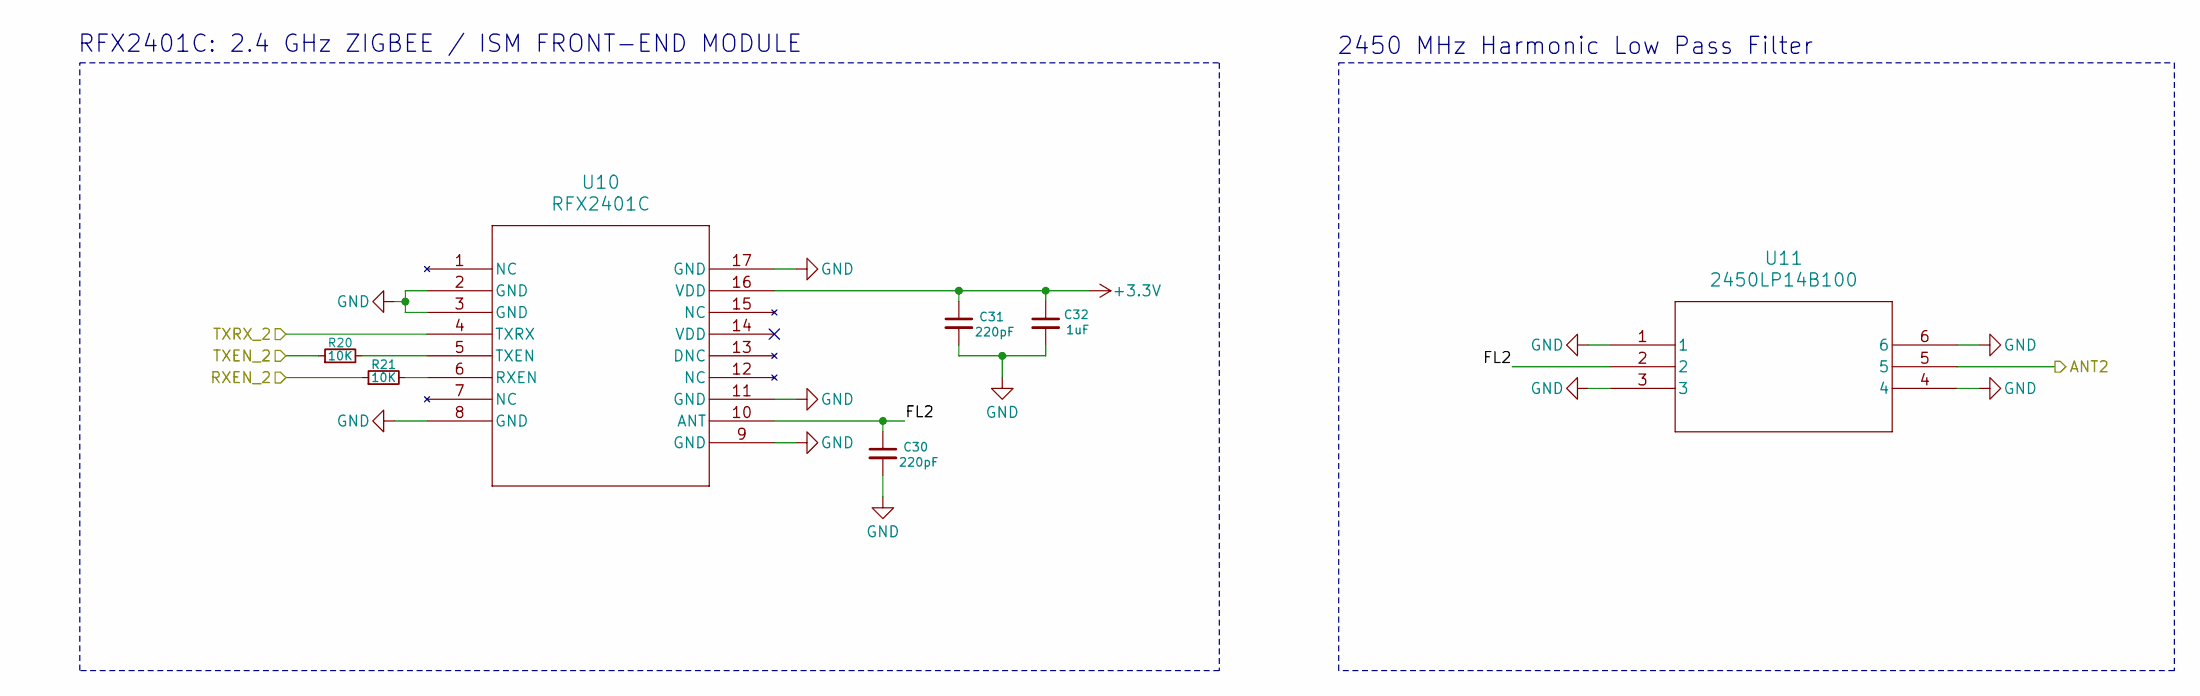
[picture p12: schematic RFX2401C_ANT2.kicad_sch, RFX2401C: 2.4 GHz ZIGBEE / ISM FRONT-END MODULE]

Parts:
C30, C31: 220pF; C_0603_1608Metric_Pad1.08x0.95mm_HandSolder
C32: 1uF; C_0603_1608Metric_Pad1.08x0.95mm_HandSolder
R20, R21: 10K; R_0603_1608Metric_Pad0.98x0.95mm_HandSolder
U10: RFX2401C; RFX2401C_SKY
U11: 2450LP14B100; CHIP_SMD_1P6XP8_JOD

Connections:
+3.3V: C31.1, C32.1, U10.16 (VDD); also elsewhere on the board
/ESP32/RXEN_2: R21.1; also elsewhere on the board
/ESP32/TXEN_2: R20.1; also elsewhere on the board
/RFX2401C_ANT2/ANT2: U11.5; also elsewhere on the board
/RFX2401C_ANT2/FL2: C30.1, U10.10 (ANT), U11.2
/RFX2401C_ANT2/TXRX_2: U10.4 (TXRX); also elsewhere on the board
GND: C30.2, C31.2, C32.2, U10.2 (GND), U10.3 (GND), U10.8 (GND), U10.9 (GND), U10.11 (GND), U10.17 (GND), U11.1, U11.3, U11.4, U11.6; also elsewhere on the board
unnamed: R21.2, U10.6 (RXEN)
unnamed: R20.2, U10.5 (TXEN)

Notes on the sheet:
RFX2401C: 2.4 GHz ZIGBEE / ISM FRONT-END MODULE
2450 MHz Harmonic Low Pass Filter

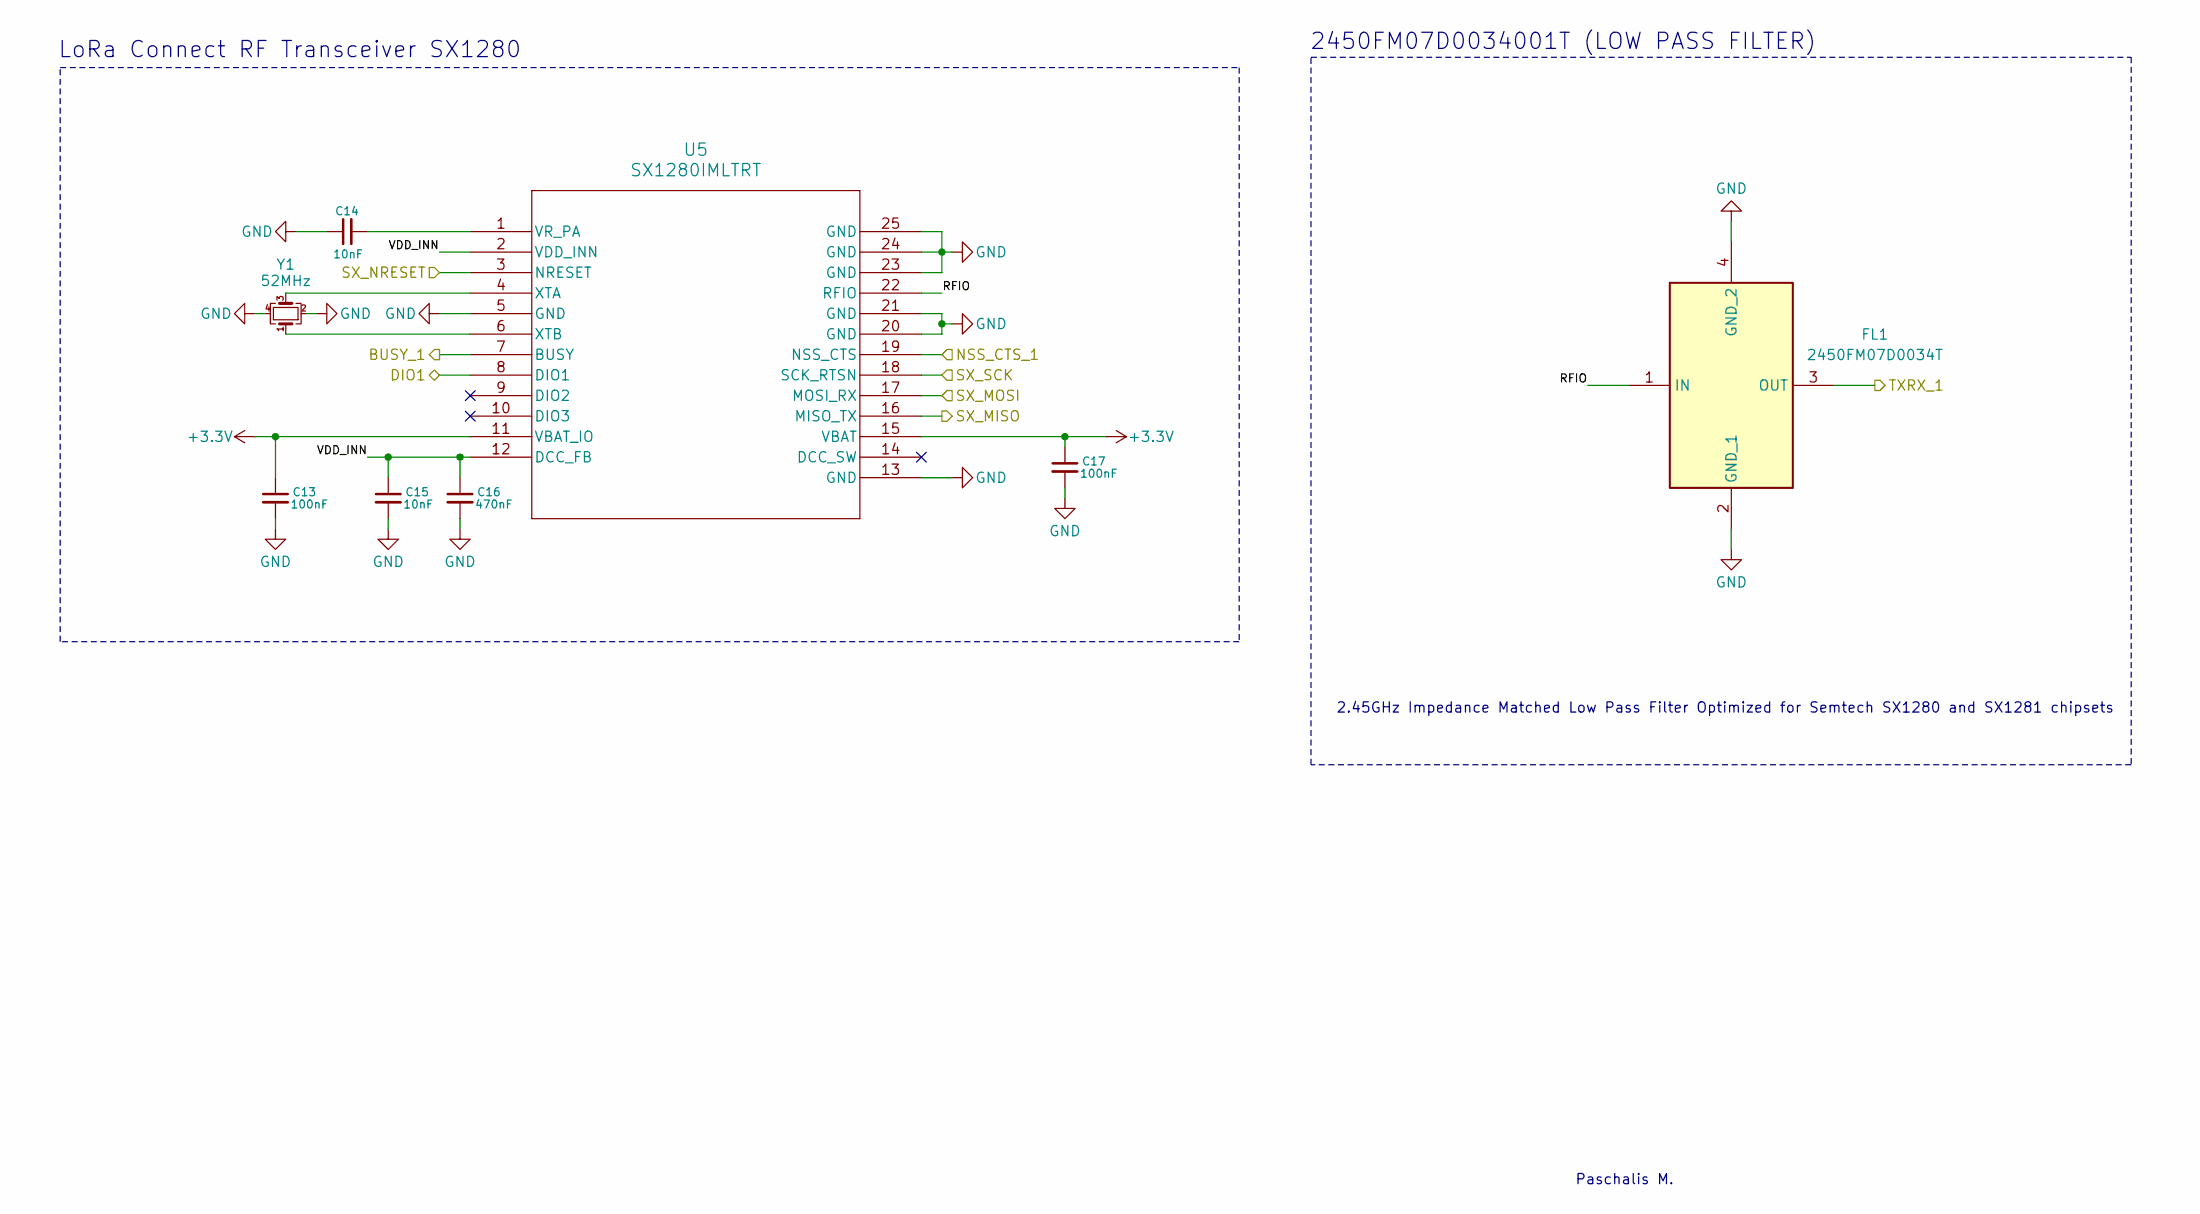
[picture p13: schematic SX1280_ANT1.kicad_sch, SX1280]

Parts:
C13, C17: 100nF; C_0603_1608Metric_Pad1.08x0.95mm_HandSolder
C14, C15: 10nF; C_0603_1608Metric_Pad1.08x0.95mm_HandSolder
C16: 470nF; C_0603_1608Metric_Pad1.08x0.95mm_HandSolder
FL1: 2450FM07D0034T; Mouser Part Number 609-2450FM07D0034T
U5: SX1280IMLTRT; QFN24_4X4_SEM
Y1: 52MHz; Crystal_SMD_2016-4Pin_2.0x1.6mm

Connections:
+3.3V: C13.1, C17.1, U5.11 (VBAT_IO), U5.15 (VBAT); also elsewhere on the board
/BUSY_1: U5.7 (BUSY); also elsewhere on the board
/ESP32/DIO1: U5.8 (DIO1); also elsewhere on the board
/ESP32/NSS_CTS_1: U5.19 (NSS_CTS); also elsewhere on the board
/MISO: U5.16 (MISO_TX); also elsewhere on the board
/MOSI: U5.17 (MOSI_RX); also elsewhere on the board
/RESET: U5.3 (NRESET); also elsewhere on the board
/RFX2401C_ANT1/TXRX_1: FL1.3 (OUT); also elsewhere on the board
/SCK: U5.18 (SCK_RTSN); also elsewhere on the board
/SX1280_ANT1/RFIO: FL1.1 (IN), U5.22 (RFIO)
/SX1280_ANT1/VDD_INN: C15.1, C16.1, U5.2 (VDD_INN), U5.12 (DCC_FB)
GND: C13.2, C14.1, C15.2, C16.2, C17.2, FL1.2 (GND_1), FL1.4 (GND_2), U5.5 (GND), U5.13 (GND), U5.20 (GND), U5.21 (GND), U5.23 (GND), U5.24 (GND), U5.25 (GND), Y1.2, Y1.4; also elsewhere on the board
unnamed: C14.2, U5.1 (VR_PA)
unnamed: U5.4 (XTA), Y1.3
unnamed: U5.6 (XTB), Y1.1

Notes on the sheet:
2450FM07D0034001T (LOW PASS FILTER)
2.45GHz Impedance Matched Low Pass Filter Optimized for Semtech SX1280 and SX1281 chipsets
LoRa Connect RF Transceiver SX1280
Paschalis M.

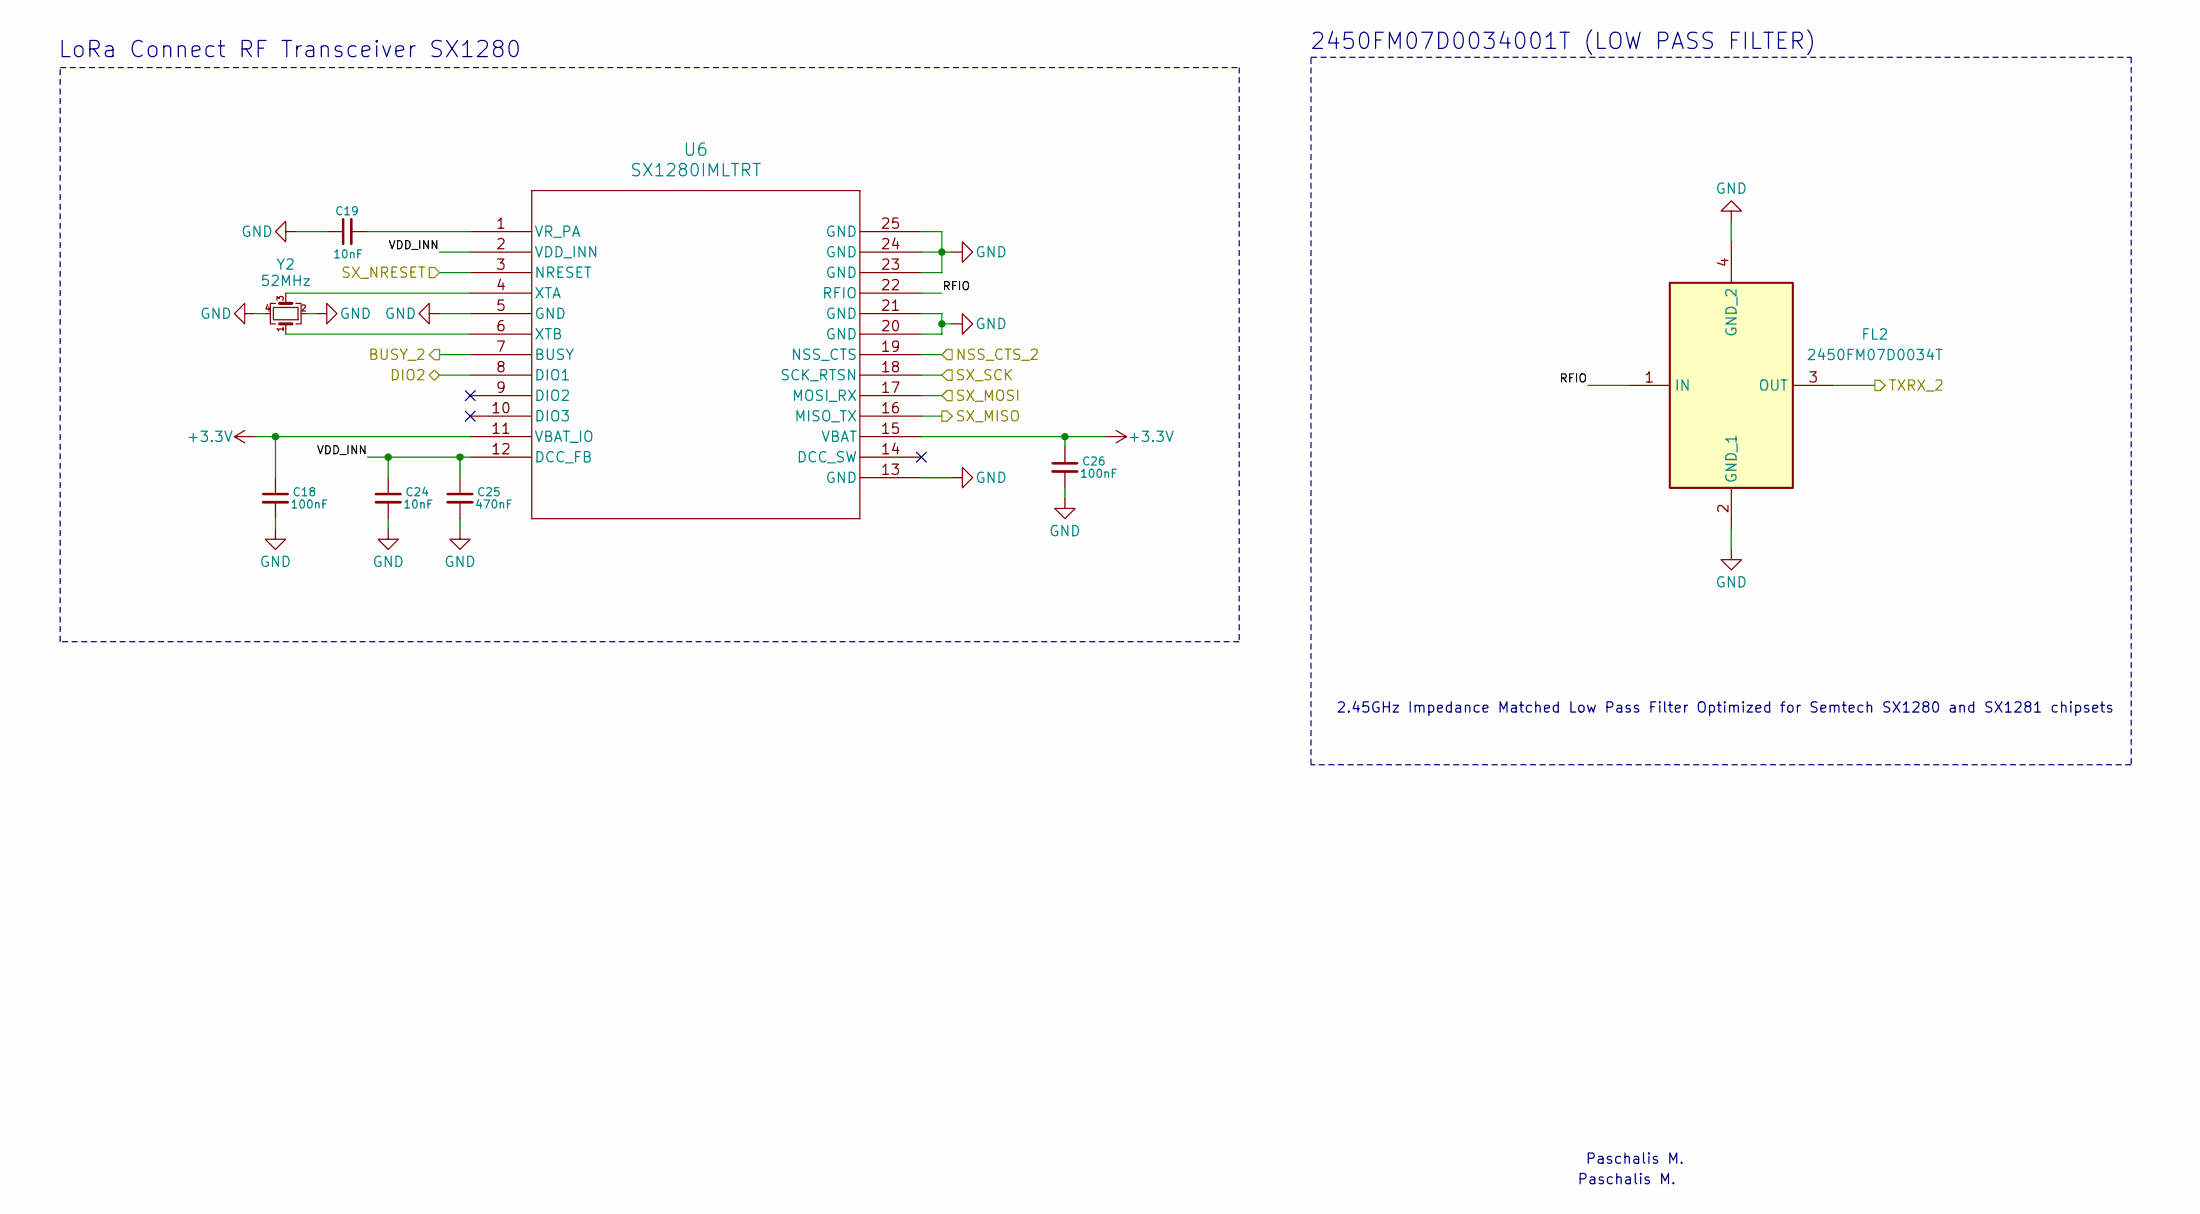
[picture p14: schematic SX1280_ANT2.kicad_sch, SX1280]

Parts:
C18, C26: 100nF; C_0603_1608Metric_Pad1.08x0.95mm_HandSolder
C19, C24: 10nF; C_0603_1608Metric_Pad1.08x0.95mm_HandSolder
C25: 470nF; C_0603_1608Metric_Pad1.08x0.95mm_HandSolder
FL2: 2450FM07D0034T; Mouser Part Number 609-2450FM07D0034T
U6: SX1280IMLTRT; QFN24_4X4_SEM
Y2: 52MHz; Crystal_SMD_2016-4Pin_2.0x1.6mm

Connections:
+3.3V: C18.1, C26.1, U6.11 (VBAT_IO), U6.15 (VBAT); also elsewhere on the board
/BUSY_2: U6.7 (BUSY); also elsewhere on the board
/ESP32/DIO2: U6.8 (DIO1); also elsewhere on the board
/ESP32/NSS_CTS_2: U6.19 (NSS_CTS); also elsewhere on the board
/MISO: U6.16 (MISO_TX); also elsewhere on the board
/MOSI: U6.17 (MOSI_RX); also elsewhere on the board
/RESET: U6.3 (NRESET); also elsewhere on the board
/RFX2401C_ANT2/TXRX_2: FL2.3 (OUT); also elsewhere on the board
/SCK: U6.18 (SCK_RTSN); also elsewhere on the board
/SX1280_ANT2/RFIO: FL2.1 (IN), U6.22 (RFIO)
/SX1280_ANT2/VDD_INN: C24.1, C25.1, U6.2 (VDD_INN), U6.12 (DCC_FB)
GND: C18.2, C19.1, C24.2, C25.2, C26.2, FL2.2 (GND_1), FL2.4 (GND_2), U6.5 (GND), U6.13 (GND), U6.20 (GND), U6.21 (GND), U6.23 (GND), U6.24 (GND), U6.25 (GND), Y2.2, Y2.4; also elsewhere on the board
unnamed: C19.2, U6.1 (VR_PA)
unnamed: U6.4 (XTA), Y2.3
unnamed: U6.6 (XTB), Y2.1

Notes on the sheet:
Paschalis M.
LoRa Connect RF Transceiver SX1280
2450FM07D0034001T (LOW PASS FILTER)
2.45GHz Impedance Matched Low Pass Filter Optimized for Semtech SX1280 and SX1281 chipsets

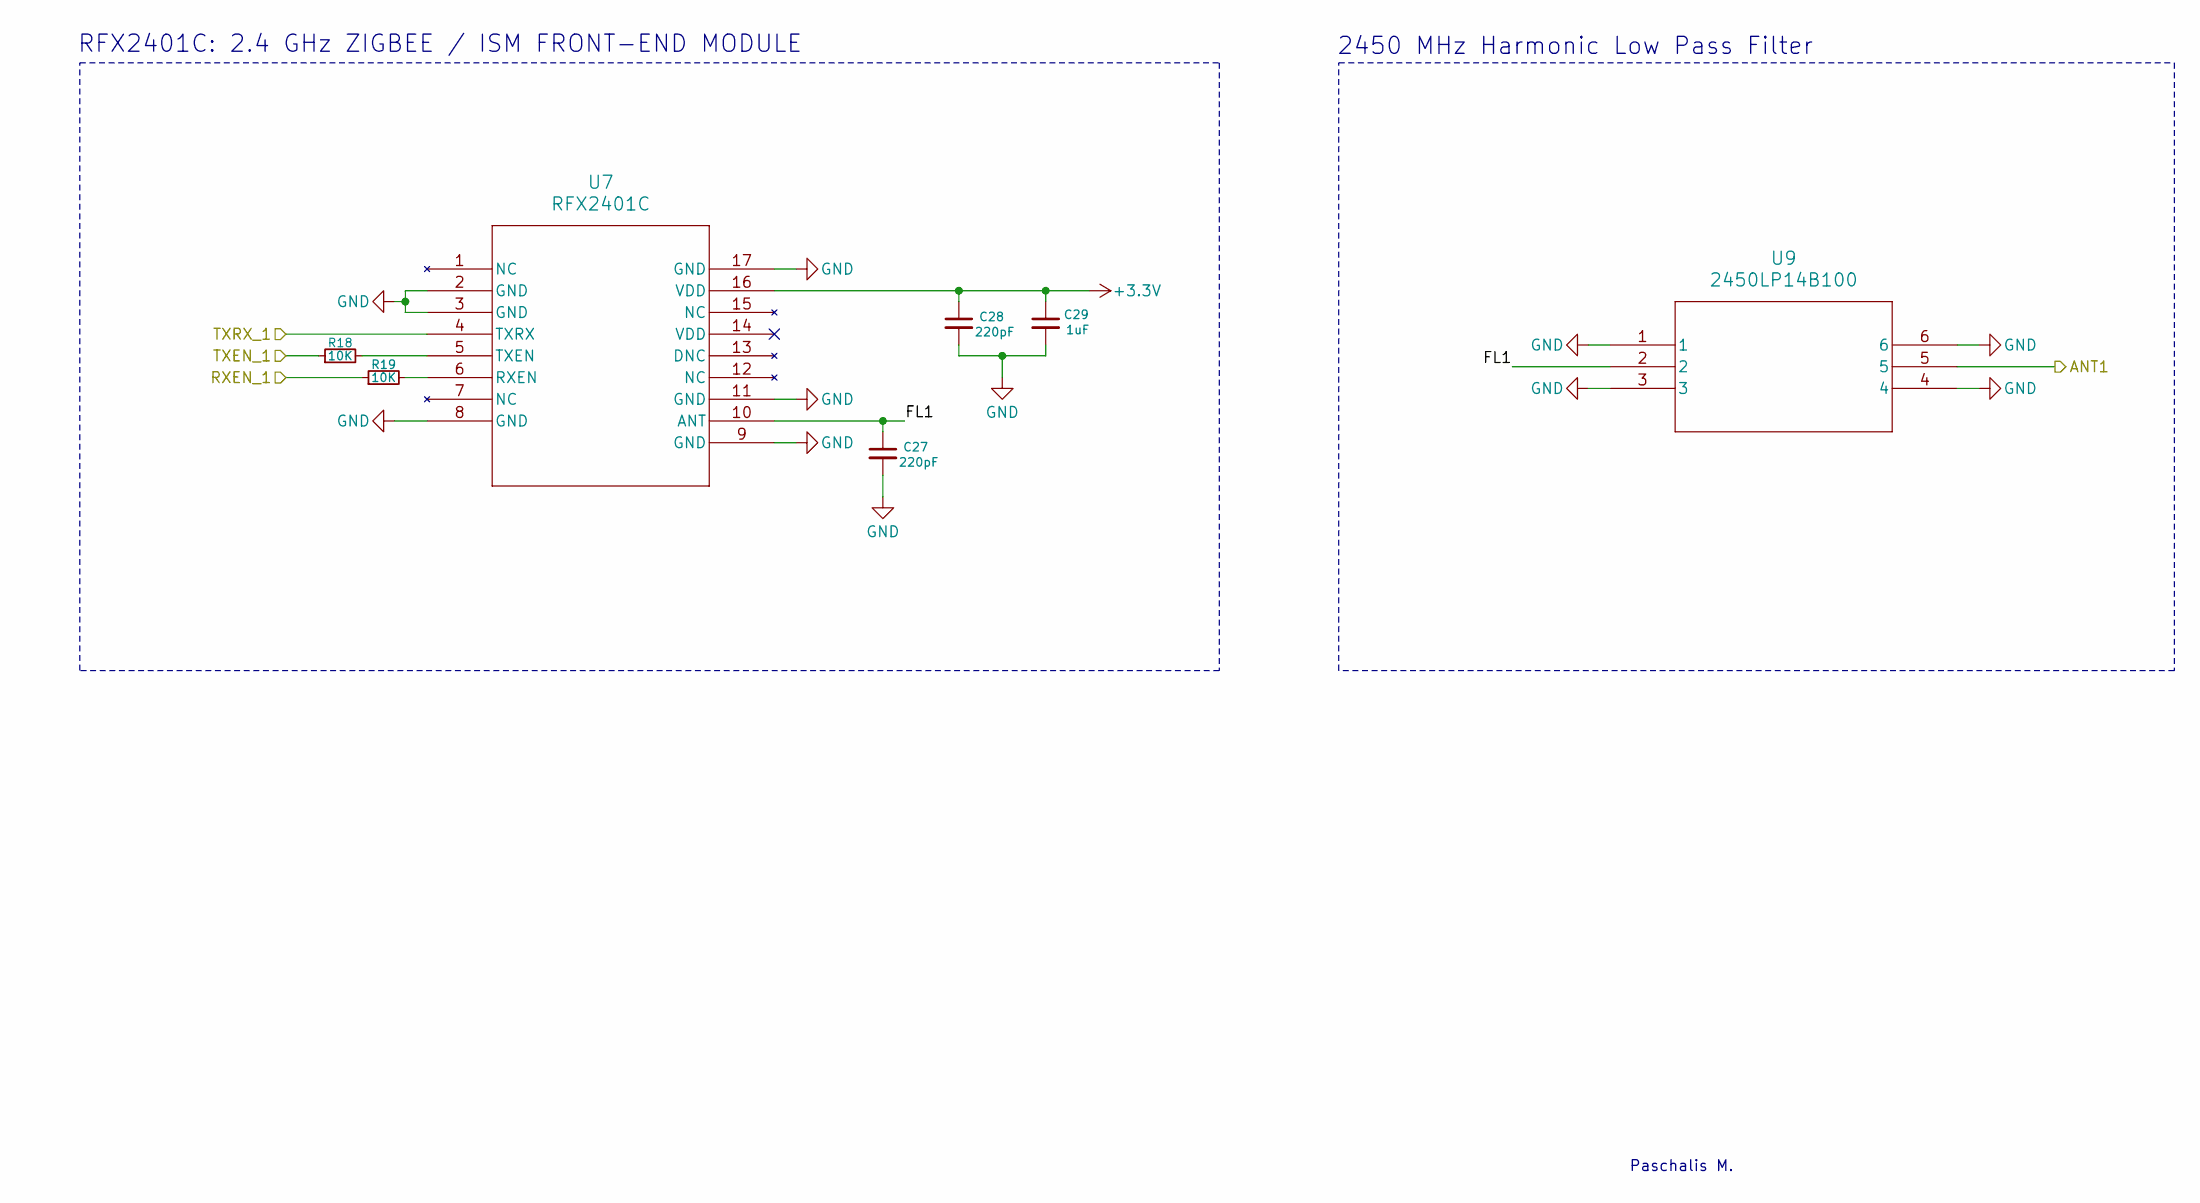
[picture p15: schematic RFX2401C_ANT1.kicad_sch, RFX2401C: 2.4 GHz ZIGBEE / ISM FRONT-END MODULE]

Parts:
C27, C28: 220pF; C_0603_1608Metric_Pad1.08x0.95mm_HandSolder
C29: 1uF; C_0603_1608Metric_Pad1.08x0.95mm_HandSolder
R18, R19: 10K; R_0603_1608Metric_Pad0.98x0.95mm_HandSolder
U7: RFX2401C; RFX2401C_SKY
U9: 2450LP14B100; CHIP_SMD_1P6XP8_JOD

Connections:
+3.3V: C28.1, C29.1, U7.16 (VDD); also elsewhere on the board
/ESP32/RXEN_1: R19.1; also elsewhere on the board
/ESP32/TXEN_1: R18.1; also elsewhere on the board
/RFX2401C_ANT1/ANT1: U9.5; also elsewhere on the board
/RFX2401C_ANT1/FL1: C27.1, U7.10 (ANT), U9.2
/RFX2401C_ANT1/TXRX_1: U7.4 (TXRX); also elsewhere on the board
GND: C27.2, C28.2, C29.2, U7.2 (GND), U7.3 (GND), U7.8 (GND), U7.9 (GND), U7.11 (GND), U7.17 (GND), U9.1, U9.3, U9.4, U9.6; also elsewhere on the board
unnamed: R19.2, U7.6 (RXEN)
unnamed: R18.2, U7.5 (TXEN)

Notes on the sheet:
2450 MHz Harmonic Low Pass Filter
Paschalis M.
RFX2401C: 2.4 GHz ZIGBEE / ISM FRONT-END MODULE

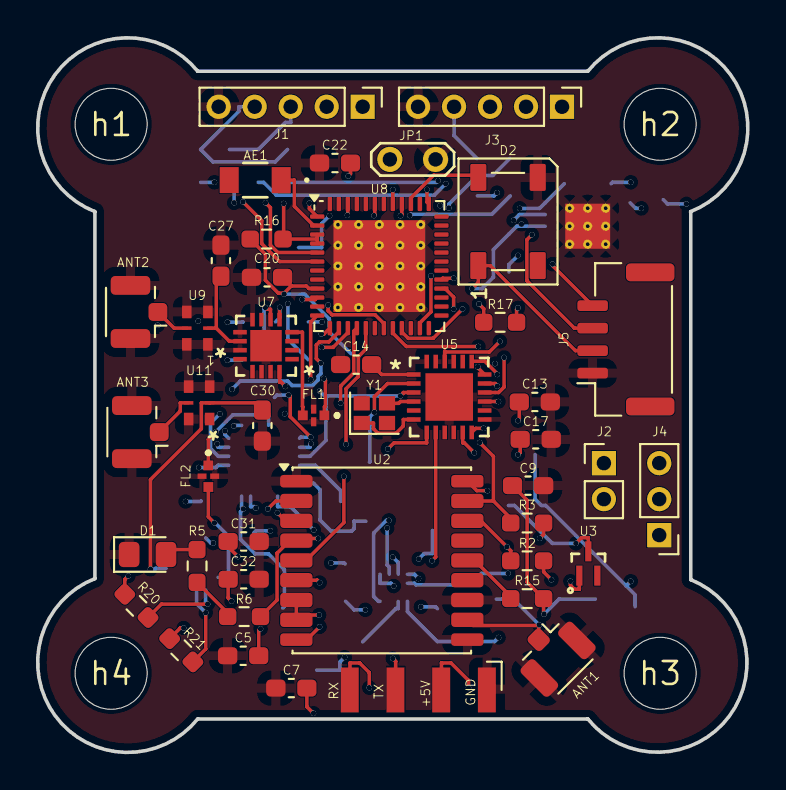
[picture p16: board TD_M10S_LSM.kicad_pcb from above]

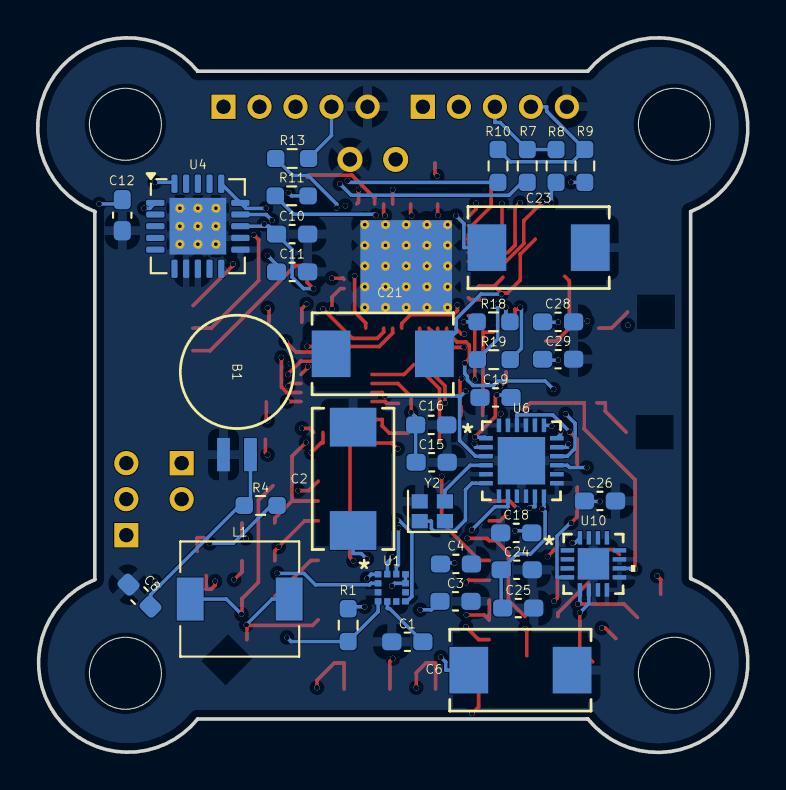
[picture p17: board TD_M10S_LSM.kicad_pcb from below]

Board: 4 copper layers, 39.4 x 39.7 mm, 85 parts (37 on the bottom side), 71 nets.

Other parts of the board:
h1, h2, h3, h4: MountingHole_4mm

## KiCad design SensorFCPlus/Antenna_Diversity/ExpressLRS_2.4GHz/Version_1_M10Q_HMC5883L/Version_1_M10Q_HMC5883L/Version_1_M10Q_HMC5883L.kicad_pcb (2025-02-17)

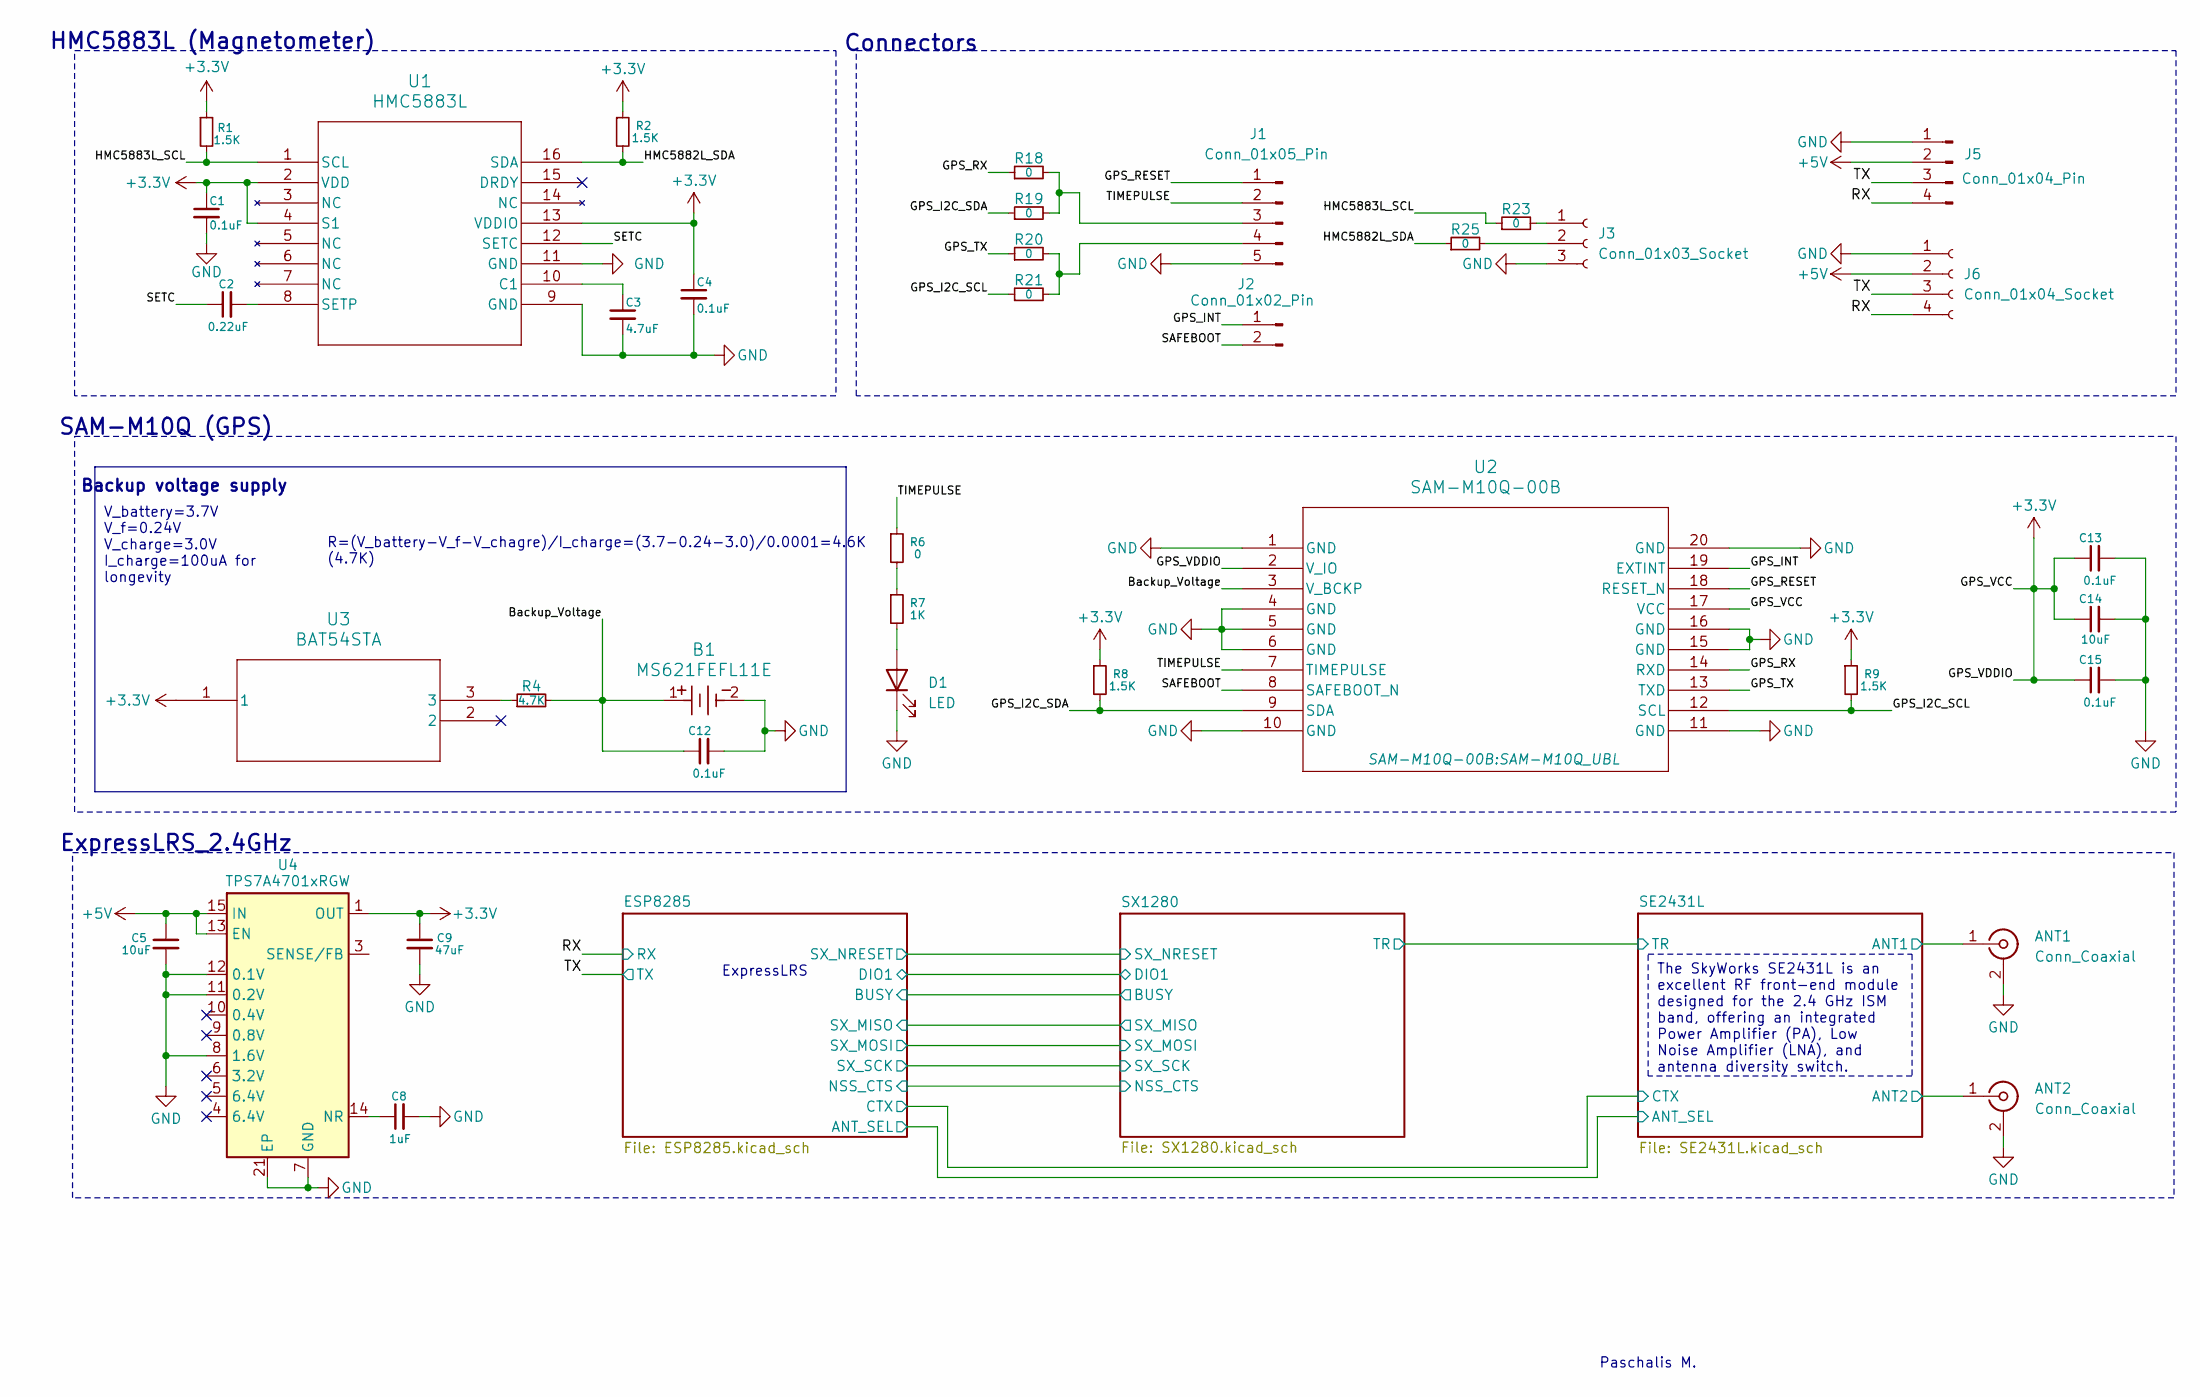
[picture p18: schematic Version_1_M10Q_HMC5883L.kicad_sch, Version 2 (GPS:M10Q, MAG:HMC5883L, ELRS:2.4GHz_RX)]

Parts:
ANT1, ANT2: Conn_Coaxial; U.FL_Hirose_U.FL-R-SMT-1_Vertical
B1: MS621FEFL11E; MS621FE-FL11E
C1, C4, C12, C13, C15: 0.1uF; C_0805_2012Metric_Pad1.18x1.45mm_HandSolder
C2: 0.22uF; C_0805_2012Metric_Pad1.18x1.45mm_HandSolder
C3: 4.7uF; C_0805_2012Metric_Pad1.18x1.45mm_HandSolder
C5: 10uF; C_0805_2012Metric_Pad1.18x1.45mm_HandSolder
C8: 1uF; C_0805_2012Metric_Pad1.18x1.45mm_HandSolder
C9: 47uF; C_0805_2012Metric_Pad1.18x1.45mm_HandSolder
C14: 10uF; ECASD40J106M055K00
D1: LED; LED_0805_2012Metric_Pad1.15x1.40mm_HandSolder
J1: Conn_01x05_Pin; PinHeader_1x05_P2.00mm_Vertical
J2: Conn_01x02_Pin; PinHeader_1x02_P2.00mm_Vertical
J3: Conn_01x03_Socket; JST_GH_SM03B-GHS-TB_1x03-1MP_P1.25mm_Horizontal
J5: Conn_01x04_Pin; JST_GH_SM04B-GHS-TB_1x04-1MP_P1.25mm_Horizontal
J6: Conn_01x04_Socket; Harwin_M20-89004xx_1x04_P2.54mm_Horizontal
R1, R2, R8, R9: 1.5K; R_0805_2012Metric_Pad1.20x1.40mm_HandSolder
R4: 4.7K; R_0805_2012Metric_Pad1.20x1.40mm_HandSolder
R6: 0; R_0805_2012Metric_Pad1.20x1.40mm_HandSolder
R7: 1K; R_0805_2012Metric_Pad1.20x1.40mm_HandSolder
R18, R19, R20, R21, R23, R25: 0; R_0603_1608Metric_Pad0.98x0.95mm_HandSolder
U1: HMC5883L; LPCC16_HNW
U2: SAM-M10Q-00B; SAM-M10Q_UBL
U3: BAT54STA
U4: TPS7A4701xRGW; Texas_RGW0020A_VQFN-20-1EP_5x5mm_P0.65mm_EP3.15x3.15mm_Ther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

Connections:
+3.3V: C1.1, C4.1, C9.1, C13.1, C14.1, C15.1, R1.1, R2.1, R8.1, R9.1, U1.2 (VDD), U1.4 (S1), U1.13 (VDDIO), U2.2 (V_IO), U2.17 (VCC), U3.1, U4.1 (OUT), U4.20 (OUT); also elsewhere on the board
+5V: C5.1, J5.2, J6.2, U4.13 (EN), U4.15 (IN), U4.16 (IN)
/Backup_Voltage: B1.1, C12.1, R4.2, U2.3 (V_BCKP)
/GPS_I2C_SCL: R9.2, R21.1, U2.12 (SCL)
/GPS_I2C_SDA: R8.2, R19.1, U2.9 (SDA)
/GPS_INT: J2.1, U2.19 (EXTINT)
/GPS_RESET: J1.1, U2.18 (RESET_N)
/GPS_RX: R18.1, U2.14 (RXD)
/GPS_TX: R20.1, U2.13 (TXD)
/HMC5882L_SDA: R2.2, R25.1, U1.16 (SDA)
/HMC5883L_SCL: R1.2, R23.1, U1.1 (SCL)
/RX: J5.4, J6.4; also elsewhere on the board
/SAFEBOOT: J2.2, U2.8 (SAFEBOOT_N)
/SE2431L/ANT1: ANT1.1 (In); also elsewhere on the board
/SE2431L/ANT2: ANT2.1 (In); also elsewhere on the board
/SETC: C2.1, U1.12 (SETC)
/TIMEPULSE: J1.2, R6.1, U2.7 (TIMEPULSE)
/TX: J5.3, J6.3; also elsewhere on the board
GND: ANT1.2 (Ext), ANT2.2 (Ext), B1.2, C1.2, C3.2, C4.2, C5.2, C8.2, C9.2, C12.2, C13.2, C14.2, C15.2, D1.1 (K), J1.5, J3.3, J5.1, J6.1, U1.9 (GND), U1.11 (GND), U2.1 (GND), U2.4 (GND), U2.5 (GND), U2.6 (GND), U2.10 (GND), U2.11 (GND), U2.15 (GND), U2.16 (GND), U2.20 (GND), U4.7 (GND), U4.8 (1.6V), U4.11 (0.2V), U4.12 (0.1V), U4.21 (EP); also elsewhere on the board
unnamed: D1.2 (A), R7.2
unnamed: J1.3, R18.2, R19.2
unnamed: J1.4, R20.2, R21.2
unnamed: J3.1, R23.2
unnamed: J3.2, R25.2
unnamed: R4.1, U3.3
unnamed: R6.2, R7.1
unnamed: C3.1, U1.10 (C1)
unnamed: C2.2, U1.8 (SETP)
unnamed: C8.1, U4.14 (NR)

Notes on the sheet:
The SkyWorks SE2431L is an excellent RF front-end module designed for the 2.4 GHz ISM band, offering an integrated Power Amplifier (PA), Low Noise Amplifier (LNA), and antenna diversity switch.
R=(V_battery-V_f-V_chagre)/I_charge=(3.7-0.24-3.0)/0.0001=4.6K (4.7K)
V_battery=3.7V V_f=0.24V V_charge=3.0V I_charge=100uA for longevity
HMC5883L (Magnetometer)
ExpressLRS
Connectors
ExpressLRS_2.4GHz
Backup voltage supply
SAM-M10Q (GPS)
Paschalis M.

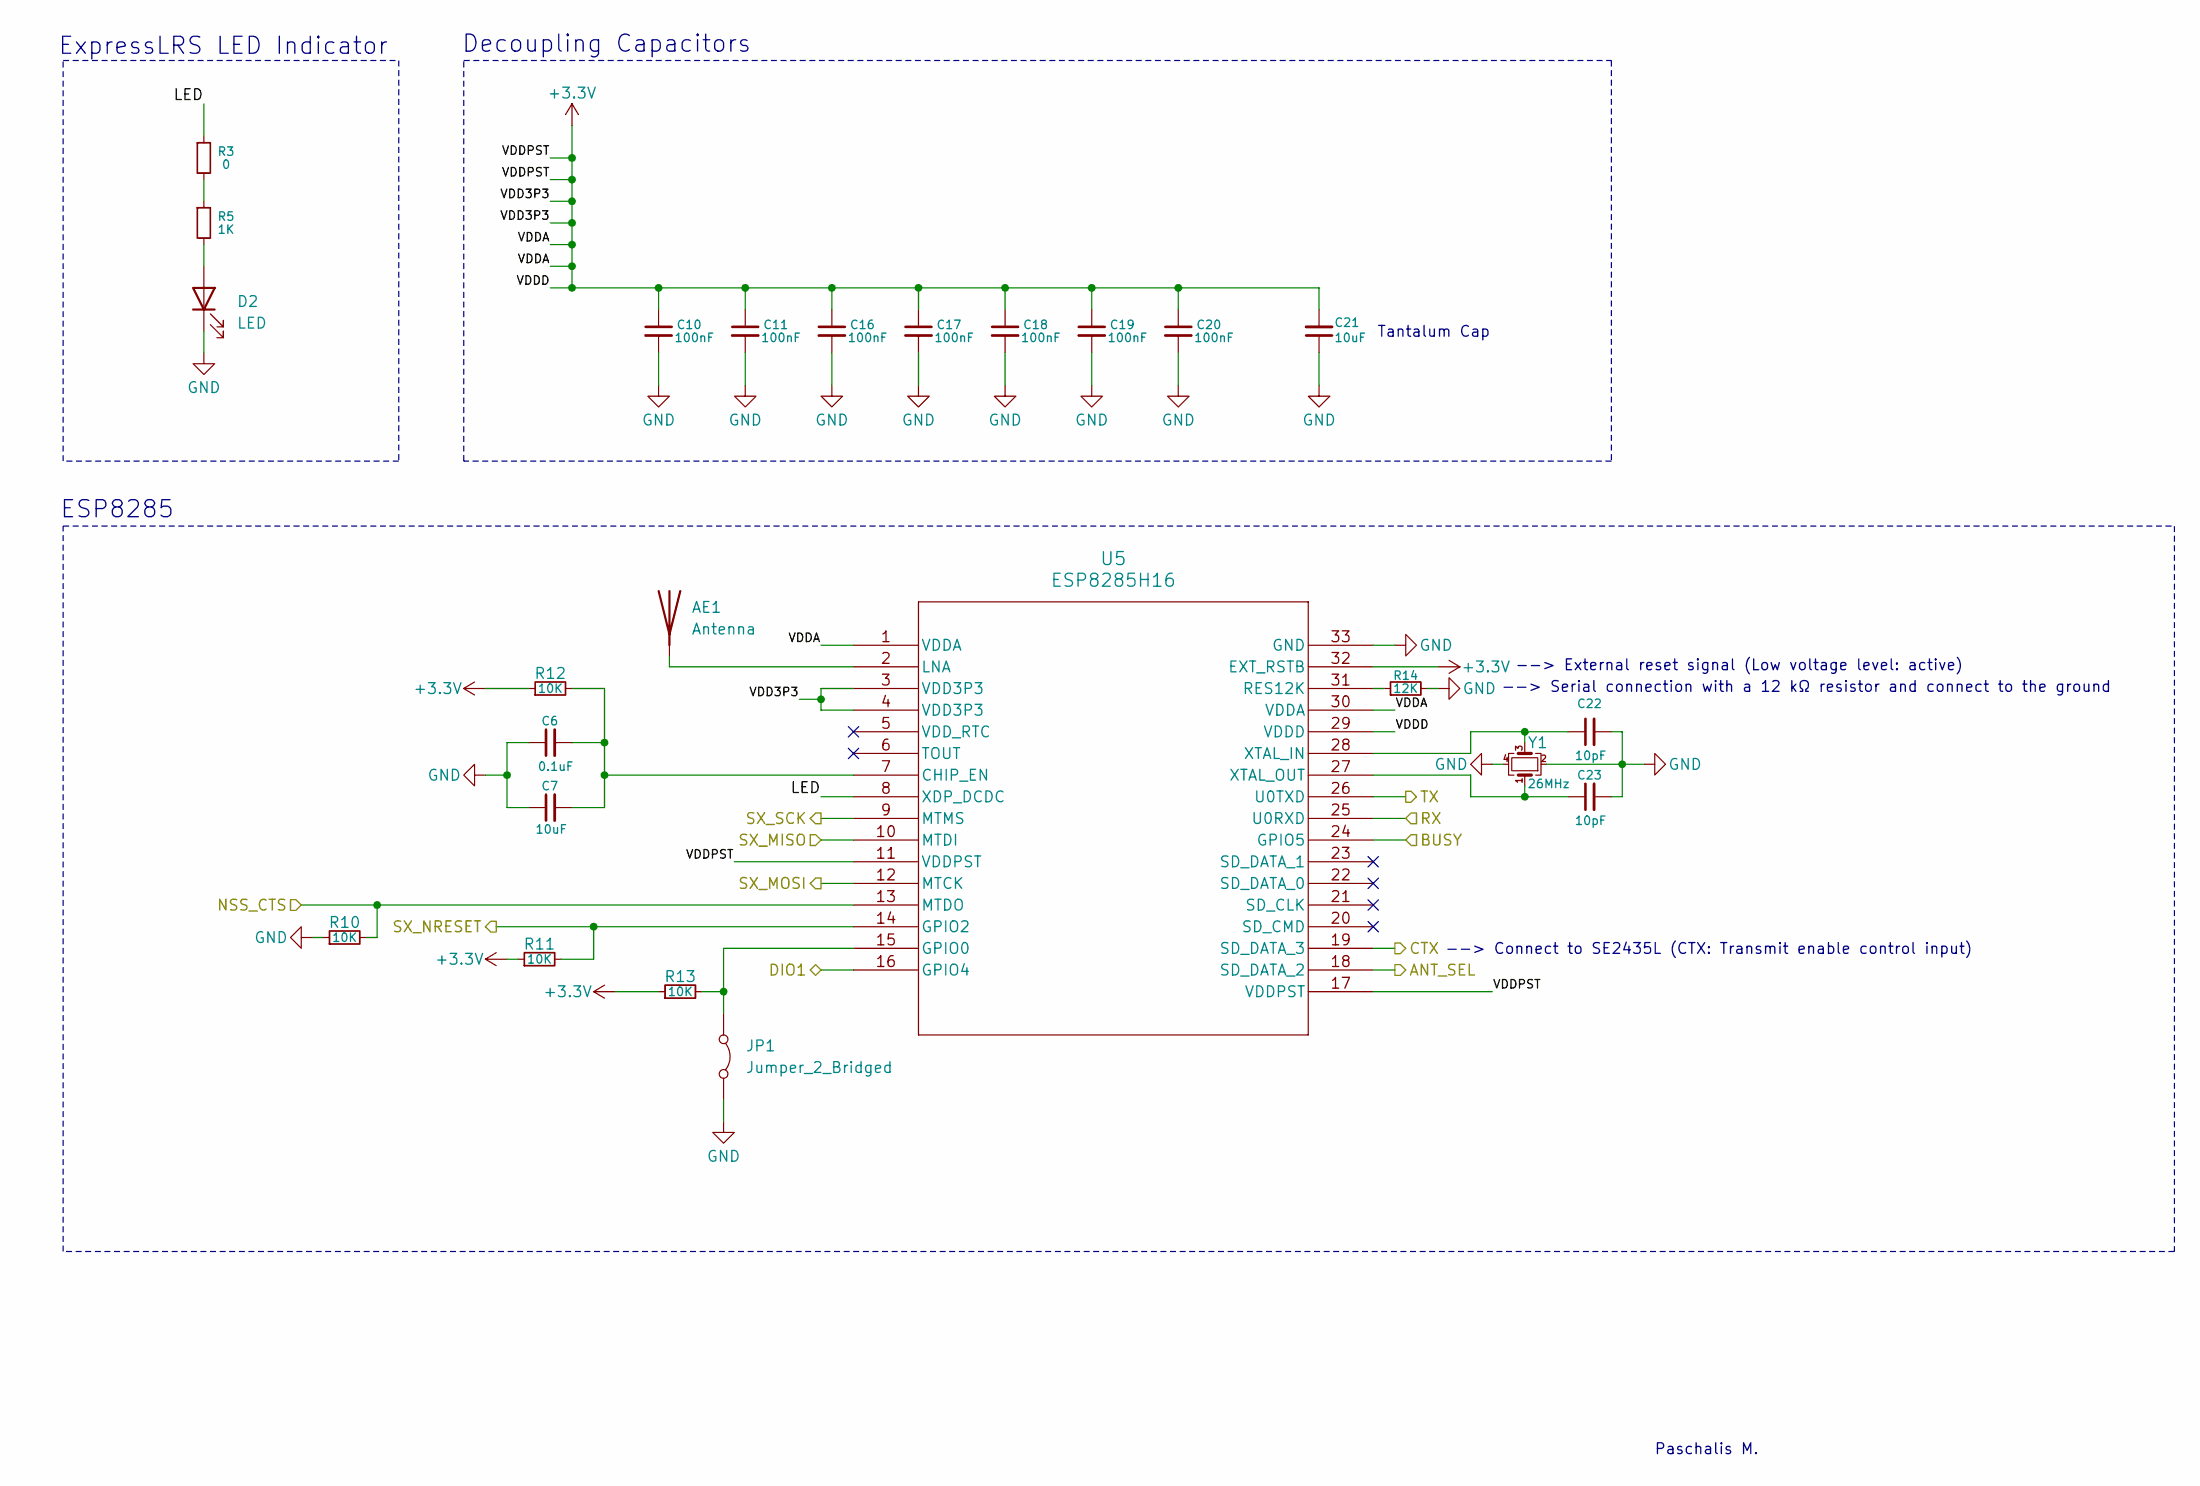
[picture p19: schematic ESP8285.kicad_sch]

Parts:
AE1: Antenna; Texas_SWRA117D_2.4GHz_Right
C6: 0.1uF; C_0805_2012Metric_Pad1.18x1.45mm_HandSolder
C7, C21: 10uF; ECASD40J106M055K00
C10, C11, C16, C17, C18, C19, C20: 100nF; C_0805_2012Metric_Pad1.18x1.45mm_HandSolder
C22, C23: 10pF; C_0805_2012Metric_Pad1.18x1.45mm_HandSolder
D2: LED; LED_0805_2012Metric_Pad1.15x1.40mm_HandSolder
JP1: Jumper_2_Bridged; SolderJumper-2_P1.3mm_Open_RoundedPad1.0x1.5mm
R3: 0; R_0805_2012Metric_Pad1.20x1.40mm_HandSolder
R5: 1K; R_0805_2012Metric_Pad1.20x1.40mm_HandSolder
R10, R11, R12, R13: 10K; R_0805_2012Metric_Pad1.20x1.40mm_HandSolder
R14: 12K; R_0805_2012Metric_Pad1.20x1.40mm_HandSolder
U5: ESP8285H16; QFN32_5X5_EXP
Y1: 26MHz; Crystal_SMD_2016-4Pin_2.0x1.6mm

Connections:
+3.3V: C10.1, C11.1, C16.1, C17.1, C18.1, C19.1, C20.1, C21.2, R11.1, R12.1, R13.1, U5.1 (VDDA), U5.3 (VDD3P3), U5.4 (VDD3P3), U5.11 (VDDPST), U5.17 (VDDPST), U5.29 (VDDD), U5.30 (VDDA), U5.32 (EXT_RSTB); also elsewhere on the board
/ESP8285/ANT_SEL: U5.18 (SD_DATA_2); also elsewhere on the board
/ESP8285/BUSY: U5.24 (GPIO5); also elsewhere on the board
/ESP8285/CTX: U5.19 (SD_DATA_3); also elsewhere on the board
/ESP8285/DIO1: U5.16 (GPIO4); also elsewhere on the board
/ESP8285/LED: R3.1, U5.8 (XDP_DCDC)
/ESP8285/NSS_CTS: R10.2, U5.13 (MTDO); also elsewhere on the board
/ESP8285/SX_MISO: U5.10 (MTDI); also elsewhere on the board
/ESP8285/SX_MOSI: U5.12 (MTCK); also elsewhere on the board
/ESP8285/SX_NRESET: R11.2, U5.14 (GPIO2); also elsewhere on the board
/ESP8285/SX_SCK: U5.9 (MTMS); also elsewhere on the board
/RX: U5.25 (U0RXD); also elsewhere on the board
/TX: U5.26 (U0TXD); also elsewhere on the board
GND: C6.1, C7.1, C10.2, C11.2, C16.2, C17.2, C18.2, C19.2, C20.2, C21.1, C22.2, C23.2, D2.1 (K), JP1.2 (B), R10.1, R14.2, U5.33 (GND), Y1.2, Y1.4; also elsewhere on the board
unnamed: AE1.1, U5.2 (LNA)
unnamed: D2.2 (A), R5.2
unnamed: JP1.1 (A), R13.2, U5.15 (GPIO0)
unnamed: R3.2, R5.1
unnamed: C6.2, C7.2, R12.2, U5.7 (CHIP_EN)
unnamed: R14.1, U5.31 (RES12K)
unnamed: C22.1, U5.28 (XTAL_IN), Y1.3
unnamed: C23.1, U5.27 (XTAL_OUT), Y1.1

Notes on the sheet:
ESP8285
Paschalis M.
Decoupling Capacitors
--> Serial connection with a 12 kΩ resistor and connect to the ground
--> Connect to SE2435L (CTX: Transmit enable control input)
--> External reset signal (Low voltage level: active)
ExpressLRS LED Indicator
Tantalum Cap

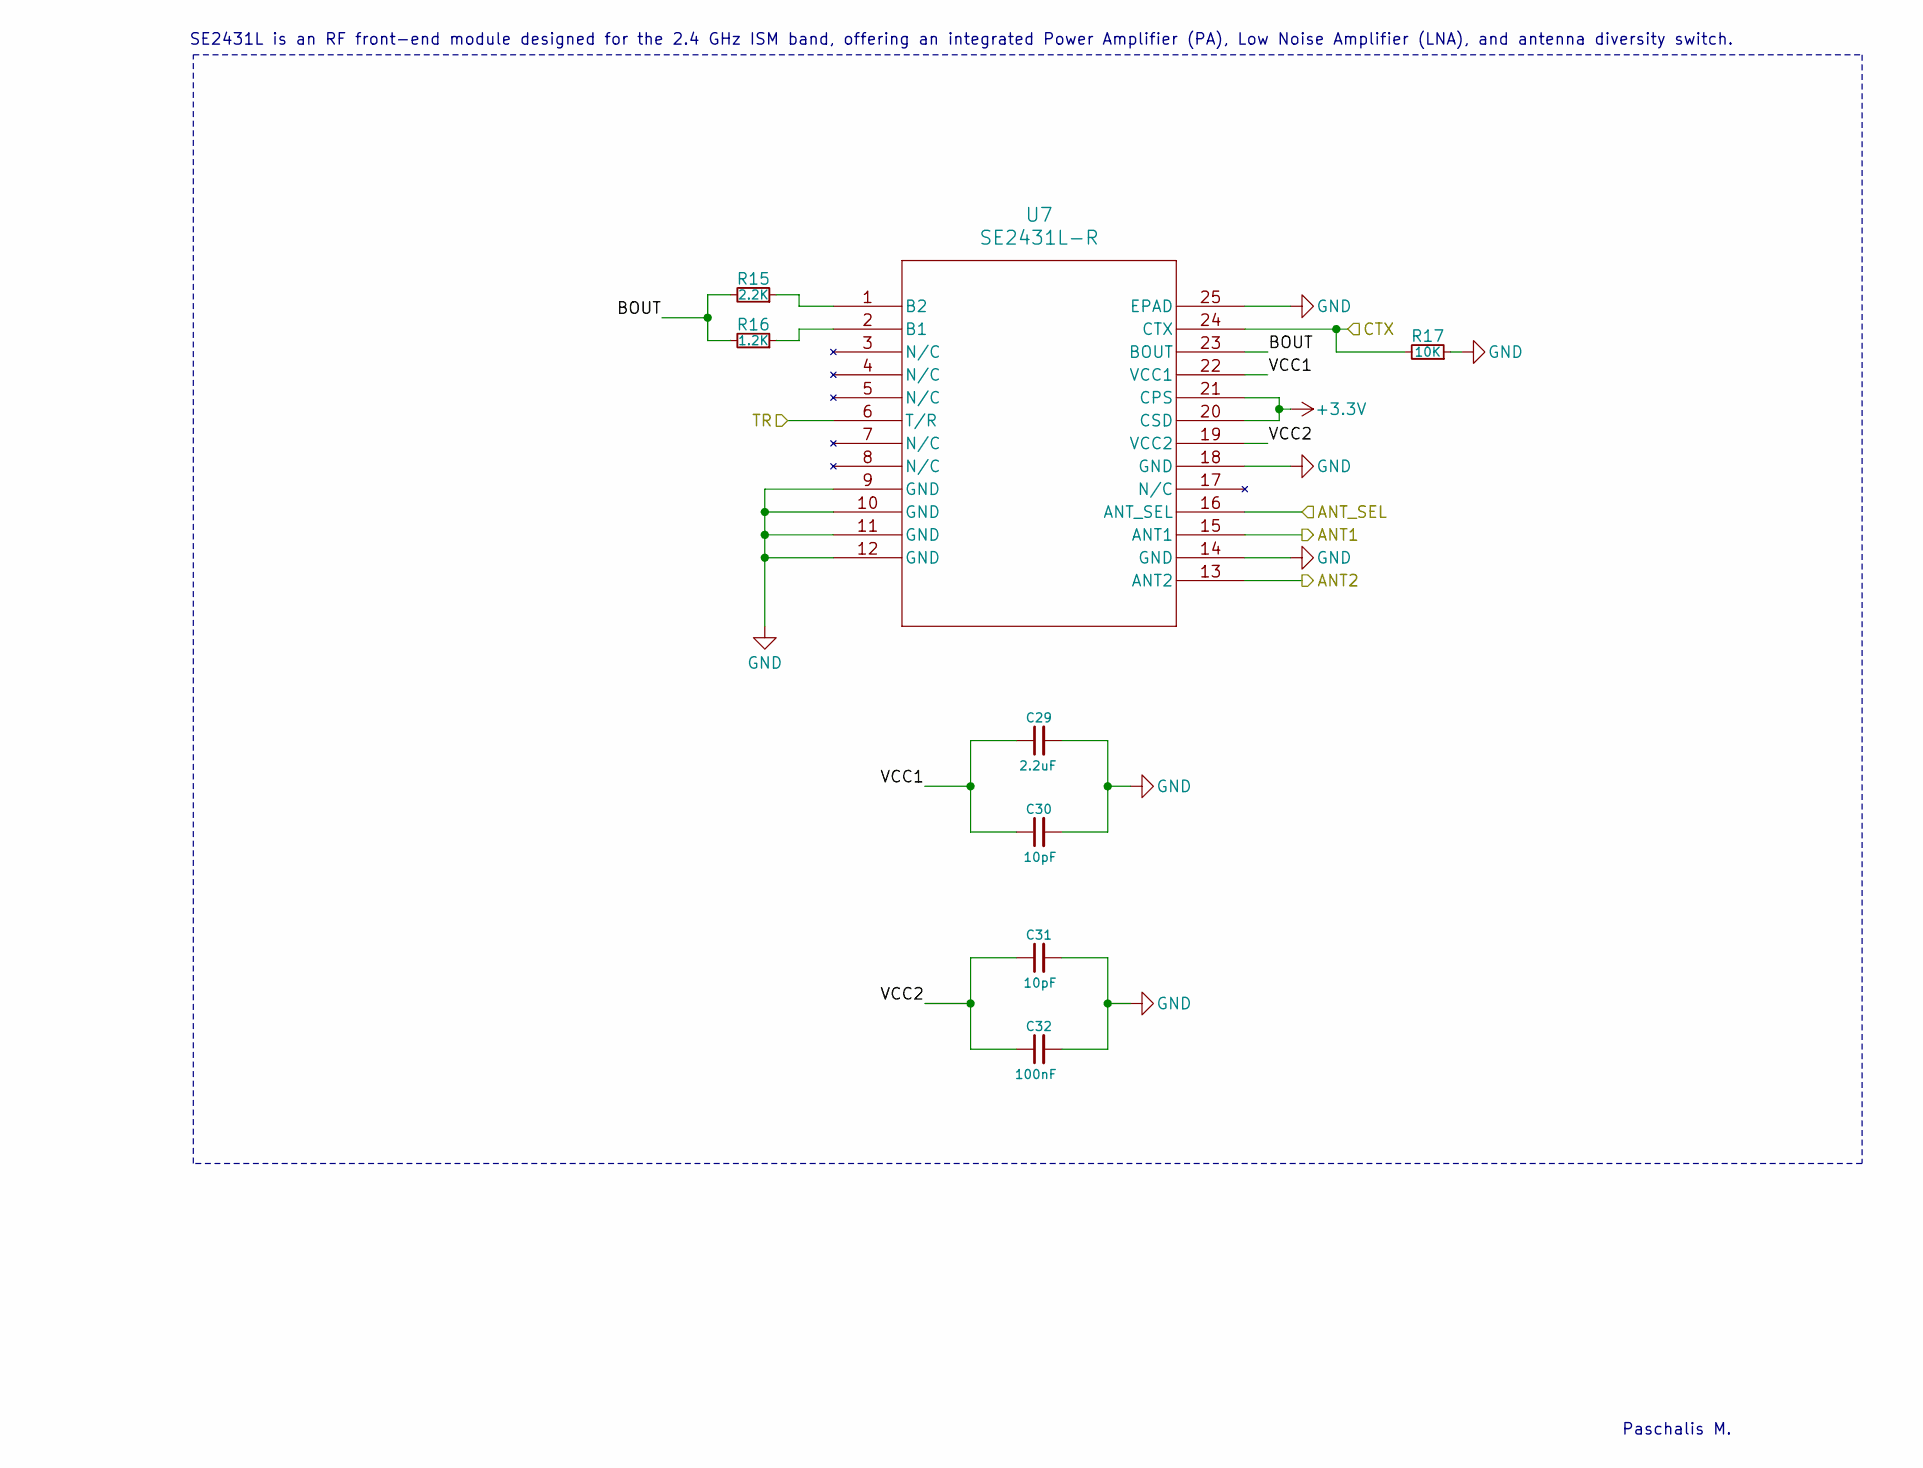
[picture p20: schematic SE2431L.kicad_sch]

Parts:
C29: 2.2uF; C_0805_2012Metric_Pad1.18x1.45mm_HandSolder
C30, C31: 10pF; C_0805_2012Metric_Pad1.18x1.45mm_HandSolder
C32: 100nF; C_0805_2012Metric_Pad1.18x1.45mm_HandSolder
R15: 2.2K; R_0805_2012Metric_Pad1.20x1.40mm_HandSolder
R16: 1.2K; R_0805_2012Metric_Pad1.20x1.40mm_HandSolder
R17: 10K; R_0805_2012Metric_Pad1.20x1.40mm_HandSolder
U7: SE2431L-R; SE2431L_SKY

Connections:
+3.3V: U7.20 (CSD), U7.21 (CPS); also elsewhere on the board
/ESP8285/ANT_SEL: U7.16 (ANT_SEL); also elsewhere on the board
/ESP8285/CTX: R17.2, U7.24 (CTX); also elsewhere on the board
/SE2431L/ANT1: U7.15 (ANT1); also elsewhere on the board
/SE2431L/ANT2: U7.13 (ANT2); also elsewhere on the board
/SE2431L/BOUT: R15.2, R16.2, U7.23 (BOUT)
/SE2431L/TR: U7.6 (T/R); also elsewhere on the board
/SE2431L/VCC1: C29.1, C30.1, U7.22 (VCC1)
/SE2431L/VCC2: C31.1, C32.1, U7.19 (VCC2)
GND: C29.2, C30.2, C31.2, C32.2, R17.1, U7.9 (GND), U7.10 (GND), U7.11 (GND), U7.12 (GND), U7.14 (GND), U7.18 (GND), U7.25 (EPAD); also elsewhere on the board
unnamed: R16.1, U7.2 (B1)
unnamed: R15.1, U7.1 (B2)

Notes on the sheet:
SE2431L is an RF front-end module designed for the 2.4 GHz ISM band, offering an integrated Power Amplifier (PA), Low Noise Amplifier (LNA), and antenna diversity switch.
Paschalis M.

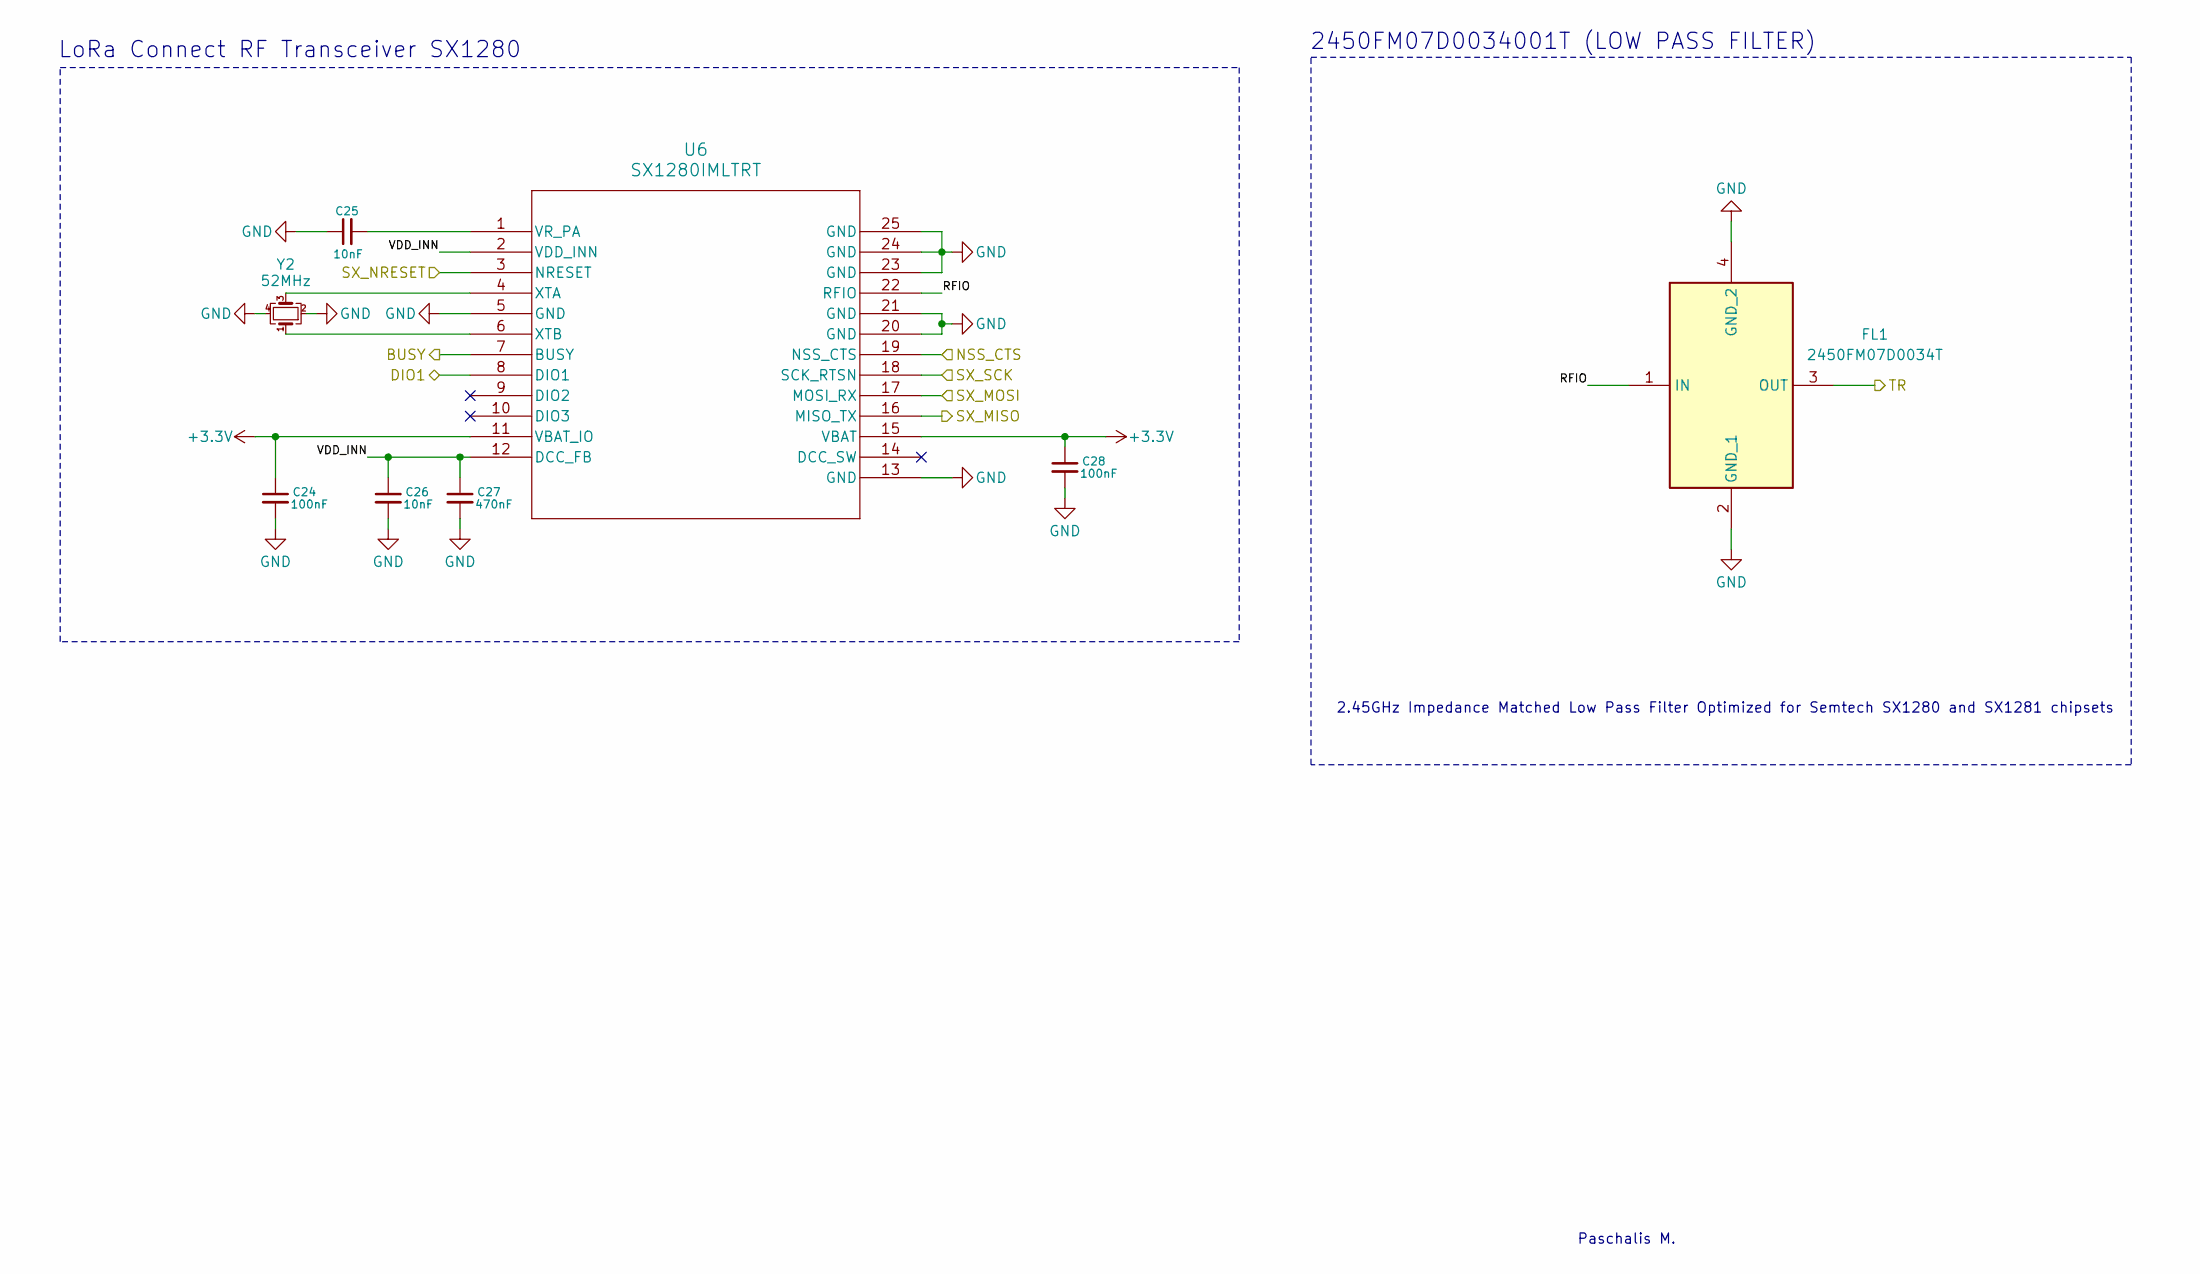
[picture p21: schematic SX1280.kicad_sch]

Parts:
C24, C28: 100nF; C_0805_2012Metric_Pad1.18x1.45mm_HandSolder
C25, C26: 10nF; C_0805_2012Metric_Pad1.18x1.45mm_HandSolder
C27: 470nF; C_0805_2012Metric_Pad1.18x1.45mm_HandSolder
FL1: 2450FM07D0034T; Mouser Part Number 609-2450FM07D0034T
U6: SX1280IMLTRT; QFN24_4X4_SEM
Y2: 52MHz; Crystal_SMD_2016-4Pin_2.0x1.6mm

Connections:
+3.3V: C24.1, C28.1, U6.11 (VBAT_IO), U6.15 (VBAT); also elsewhere on the board
/ESP8285/BUSY: U6.7 (BUSY); also elsewhere on the board
/ESP8285/DIO1: U6.8 (DIO1); also elsewhere on the board
/ESP8285/NSS_CTS: U6.19 (NSS_CTS); also elsewhere on the board
/ESP8285/SX_MISO: U6.16 (MISO_TX); also elsewhere on the board
/ESP8285/SX_MOSI: U6.17 (MOSI_RX); also elsewhere on the board
/ESP8285/SX_NRESET: U6.3 (NRESET); also elsewhere on the board
/ESP8285/SX_SCK: U6.18 (SCK_RTSN); also elsewhere on the board
/SE2431L/TR: FL1.3 (OUT); also elsewhere on the board
/SX1280/RFIO: FL1.1 (IN), U6.22 (RFIO)
/SX1280/VDD_INN: C26.1, C27.1, U6.2 (VDD_INN), U6.12 (DCC_FB)
GND: C24.2, C25.1, C26.2, C27.2, C28.2, FL1.2 (GND_1), FL1.4 (GND_2), U6.5 (GND), U6.13 (GND), U6.20 (GND), U6.21 (GND), U6.23 (GND), U6.24 (GND), U6.25 (GND), Y2.2, Y2.4; also elsewhere on the board
unnamed: C25.2, U6.1 (VR_PA)
unnamed: U6.4 (XTA), Y2.3
unnamed: U6.6 (XTB), Y2.1

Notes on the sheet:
2450FM07D0034001T (LOW PASS FILTER)
LoRa Connect RF Transceiver SX1280
2.45GHz Impedance Matched Low Pass Filter Optimized for Semtech SX1280 and SX1281 chipsets
Paschalis M.



Board: 4 copper layers, 39.4 x 39.7 mm, 80 parts (39 on the bottom side), 57 nets.

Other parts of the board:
hole1, hole2, hole3, hole4: MountingHole_4mm

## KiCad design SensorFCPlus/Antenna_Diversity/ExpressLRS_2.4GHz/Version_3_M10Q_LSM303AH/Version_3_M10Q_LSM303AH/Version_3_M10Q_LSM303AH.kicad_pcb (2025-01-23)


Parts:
ANT1, ANT2: Conn_Coaxial; U.FL_Hirose_U.FL-R-SMT-1_Vertical
B1: MS621FEFL11E; MS621FE-FL11E
C1: 220nF; C_0603_1608Metric_Pad1.08x0.95mm_HandSolder
C2, C6: 10uF; ECASD40J106M055K00
C3, C4: 0.1uF; C_0603_1608Metric_Pad1.08x0.95mm_HandSolder
C5, C7, C8: 0.1uF; C_0805_2012Metric_Pad1.18x1.45mm_HandSolder
C9: 10uF; C_0805_2012Metric_Pad1.18x1.45mm_HandSolder
C10: 1uF; C_0805_2012Metric_Pad1.18x1.45mm_HandSolder
C11: 47uF; C_0805_2012Metric_Pad1.18x1.45mm_HandSolder
D1: LED; LED_0805_2012Metric_Pad1.15x1.40mm_HandSolder
J1, J3: Conn_01x05_Pin; PinHeader_1x05_P2.00mm_Vertical
J2: Conn_01x02_Pin; PinHeader_1x02_P2.00mm_Vertical
J4: Conn_01x03_Pin; PinHeader_1x03_P2.00mm_Vertical
J5: Conn_01x04_Pin; JST_GH_SM04B-GHS-TB_1x04-1MP_P1.25mm_Horizontal
J6: Conn_01x04_Socket; Harwin_M20-89004xx_1x04_P2.54mm_Horizontal
R1: 1K; R_0603_1608Metric_Pad0.98x0.95mm_HandSolder
R2, R3: 1.5K; R_0805_2012Metric_Pad1.20x1.40mm_HandSolder
R4: 4.7K; R_0805_2012Metric_Pad1.20x1.40mm_HandSolder
R5: 1K; R_0805_2012Metric_Pad1.20x1.40mm_HandSolder
R6: 0; R_0805_2012Metric_Pad1.20x1.40mm_HandSolder
R7, R8, R9, R10, R11, R12, R13, R14: 0; R_0603_1608Metric_Pad0.98x0.95mm_HandSolder
U1: LSM303AHTR
U2: SAM-M10Q-00B; SAM-M10Q_UBL
U3: BAT54STA; SOT23_BAT54STA_1P7XP85_DIO
U4: TPS7A4701xRGW; Texas_RGW0020A_VQFN-20-1EP_5x5mm_P0.65mm_EP3.15x3.15mm_Ther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

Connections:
+3.3V: C2.1, C3.1, C4.1, C5.1, C6.1, C7.1, C11.1, R2.1, R3.1, U1.9 (Vdd), U1.10 (Vdd_IO), U2.2 (V_IO), U2.17 (VCC), U3.1, U4.1 (OUT), U4.20 (OUT); also elsewhere on the board
+5V: C9.1, J5.2, J6.2, U4.13 (EN), U4.15 (IN), U4.16 (IN)
/Backup_Voltage: B1.1, C8.1, R4.2, U2.3 (V_BCKP)
/GPS_I2C_SCL: R3.2, R10.1, U2.12 (SCL)
/GPS_I2C_SDA: R2.2, R7.1, U2.9 (SDA)
/GPS_INT: J2.1, U2.19 (EXTINT)
/GPS_RESET: J1.1, U2.18 (RESET_N)
/GPS_RX: R8.1, U2.14 (RXD)
/GPS_TX: R9.1, U2.13 (TXD)
/MAG_CS0: J3.1, U1.2 (CS)
/MAG_INT1: J4.1, U1.12 (INT1_XL)
/MAG_INT2: J4.2, U1.11 (INT2_XL)
/MAG_MISO: J3.2, R1.2, U1.4 (SDA/SDI/SDO)
/MAG_MOSI: R1.1, R13.1
/MAG_READY: J4.3, U1.7 (INT_MAG/DRDY)
/MAG_SCK: R11.1, U1.1 (SCL/SPC)
/MAG_SCL: R12.1
/MAG_SDA: R14.1
/RX: J5.4, J6.4; also elsewhere on the board
/SAFEBOOT: J2.2, U2.8 (SAFEBOOT_N)
/SE2431L/ANT1: ANT1.1 (In); also elsewhere on the board
/SE2431L/ANT2: ANT2.1 (In); also elsewhere on the board
/TIMEPULSE: J1.2, R6.1, U2.7 (TIMEPULSE)
/TX: J5.3, J6.3; also elsewhere on the board
GND: ANT1.2 (Ext), ANT2.2 (Ext), B1.2, C1.1, C2.2, C3.2, C4.2, C5.2, C6.2, C7.2, C8.2, C9.2, C10.2, C11.2, D1.1 (K), J1.5, J3.5, J5.1, J6.1, U1.3 (RESERVED), U1.6 (GND), U1.8 (GND), U2.1 (GND), U2.4 (GND), U2.5 (GND), U2.6 (GND), U2.10 (GND), U2.11 (GND), U2.15 (GND), U2.16 (GND), U2.20 (GND), U4.7 (GND), U4.8 (1.6V), U4.11 (0.2V), U4.12 (0.1V), U4.21 (EP); also elsewhere on the board
unnamed: D1.2 (A), R5.2
unnamed: J1.3, R7.2, R8.2
unnamed: J1.4, R9.2, R10.2
unnamed: J3.3, R11.2, R12.2
unnamed: J3.4, R13.2, R14.2
unnamed: R4.1, U3.3
unnamed: R5.1, R6.2
unnamed: C1.2, U1.5 (C1)
unnamed: C10.1, U4.14 (NR)

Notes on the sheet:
R=(V_battery-V_f-V_chagre)/I_charge=(3.7-0.24-3.0)/0.0001=4.6K (4.7K)
The SkyWorks SE2431L is an excellent RF front-end module designed for the 2.4 GHz ISM band, offering an integrated Power Amplifier (PA), Low Noise Amplifier (LNA), and antenna diversity switch.
V_battery=3.7V V_f=0.24V V_charge=3.0V I_charge=100uA for longevity
The device core is supplied through the Vdd line while the I/O pads are supplied through the Vdd_IO line. Power supply decoupling capacitors (100 nF ceramic, 10 μF aluminum) should be placed as near as possible to pin 9 of the device (common design practice). It is possible to remove Vdd, maintaini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
SAM-M10Q (GPS)
LSM303AH (Magnetometer)
Backup voltage supply
Paschalis M.
Connectors
ExpressLRS
ExpressLRS_2.4GHz


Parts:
C24, C28: 100nF; C_0603_1608Metric_Pad1.08x0.95mm_HandSolder
C25, C26: 10nF; C_0603_1608Metric_Pad1.08x0.95mm_HandSolder
C27: 470nF; C_0603_1608Metric_Pad1.08x0.95mm_HandSolder
FL1: 2450FM07D0034T; Mouser Part Number 609-2450FM07D0034T
U6: SX1280IMLTRT; QFN24_4X4_SEM
Y2: 52MHz; Crystal_SMD_2016-4Pin_2.0x1.6mm

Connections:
+3.3V: C24.1, C28.1, U6.11 (VBAT_IO), U6.15 (VBAT); also elsewhere on the board
/ESP8285/BUSY: U6.7 (BUSY); also elsewhere on the board
/ESP8285/DIO1: U6.8 (DIO1); also elsewhere on the board
/ESP8285/NSS_CTS: U6.19 (NSS_CTS); also elsewhere on the board
/ESP8285/SX_MISO: U6.16 (MISO_TX); also elsewhere on the board
/ESP8285/SX_MOSI: U6.17 (MOSI_RX); also elsewhere on the board
/ESP8285/SX_NRESET: U6.3 (NRESET); also elsewhere on the board
/ESP8285/SX_SCK: U6.18 (SCK_RTSN); also elsewhere on the board
/SE2431L/TR: FL1.3 (OUT); also elsewhere on the board
/SX1280/RFIO: FL1.1 (IN), U6.22 (RFIO)
/SX1280/VDD_INN: C26.1, C27.1, U6.2 (VDD_INN), U6.12 (DCC_FB)
GND: C24.2, C25.1, C26.2, C27.2, C28.2, FL1.2 (GND_1), FL1.4 (GND_2), U6.5 (GND), U6.13 (GND), U6.20 (GND), U6.21 (GND), U6.23 (GND), U6.24 (GND), U6.25 (GND), Y2.2, Y2.4; also elsewhere on the board
unnamed: C25.2, U6.1 (VR_PA)
unnamed: U6.4 (XTA), Y2.3
unnamed: U6.6 (XTB), Y2.1

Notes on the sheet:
Paschalis M.
2.45GHz Impedance Matched Low Pass Filter Optimized for Semtech SX1280 and SX1281 chipsets
LoRa Connect RF Transceiver SX1280
2450FM07D0034001T (LOW PASS FILTER)


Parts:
AE1: Antenna; Texas_SWRA117D_2.4GHz_Right
C12: 0.1uF; C_0603_1608Metric_Pad1.08x0.95mm_HandSolder
C13, C21: 10uF; ECASD40J106M055K00
C14, C15, C16, C17, C18, C19, C20: 100nF; C_0805_2012Metric_Pad1.18x1.45mm_HandSolder
C22, C23: 10pF; C_0805_2012Metric_Pad1.18x1.45mm_HandSolder
D2: LED; LED_0805_2012Metric_Pad1.15x1.40mm_HandSolder
JP1: Jumper_2_Bridged; SolderJumper-2_P1.3mm_Open_RoundedPad1.0x1.5mm
R15: 0; R_0805_2012Metric_Pad1.20x1.40mm_HandSolder
R16: 1K; R_0805_2012Metric_Pad1.20x1.40mm_HandSolder
R17, R18, R20: 10K; R_0603_1608Metric_Pad0.98x0.95mm_HandSolder
R19: 10K; R_0805_2012Metric_Pad1.20x1.40mm_HandSolder
R21: 12K; R_0603_1608Metric_Pad0.98x0.95mm_HandSolder
U5: ESP8285H16; QFN32_5X5_EXP
Y1: 26MHz; Crystal_SMD_2016-4Pin_2.0x1.6mm

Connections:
+3.3V: C14.1, C15.1, C16.1, C17.1, C18.1, C19.1, C20.1, C21.2, R18.1, R19.1, R20.1, U5.1 (VDDA), U5.3 (VDD3P3), U5.4 (VDD3P3), U5.11 (VDDPST), U5.17 (VDDPST), U5.29 (VDDD), U5.30 (VDDA), U5.32 (EXT_RSTB); also elsewhere on the board
/ESP8285/ANT_SEL: U5.18 (SD_DATA_2); also elsewhere on the board
/ESP8285/BUSY: U5.24 (GPIO5); also elsewhere on the board
/ESP8285/CTX: U5.19 (SD_DATA_3); also elsewhere on the board
/ESP8285/DIO1: U5.16 (GPIO4); also elsewhere on the board
/ESP8285/LED: R15.1, U5.8 (XDP_DCDC)
/ESP8285/NSS_CTS: R17.2, U5.13 (MTDO); also elsewhere on the board
/ESP8285/SX_MISO: U5.10 (MTDI); also elsewhere on the board
/ESP8285/SX_MOSI: U5.12 (MTCK); also elsewhere on the board
/ESP8285/SX_NRESET: R18.2, U5.14 (GPIO2); also elsewhere on the board
/ESP8285/SX_SCK: U5.9 (MTMS); also elsewhere on the board
/RX: U5.25 (U0RXD); also elsewhere on the board
/TX: U5.26 (U0TXD); also elsewhere on the board
GND: C12.1, C13.1, C14.2, C15.2, C16.2, C17.2, C18.2, C19.2, C20.2, C21.1, C22.2, C23.2, D2.1 (K), JP1.2 (B), R17.1, R21.2, U5.33 (GND), Y1.2, Y1.4; also elsewhere on the board
unnamed: AE1.1, U5.2 (LNA)
unnamed: D2.2 (A), R16.2
unnamed: JP1.1 (A), R20.2, U5.15 (GPIO0)
unnamed: R15.2, R16.1
unnamed: C12.2, C13.2, R19.2, U5.7 (CHIP_EN)
unnamed: R21.1, U5.31 (RES12K)
unnamed: C22.1, U5.28 (XTAL_IN), Y1.3
unnamed: C23.1, U5.27 (XTAL_OUT), Y1.1

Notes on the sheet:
--> External reset signal (Low voltage level: active)
Decoupling Capacitors
ExpressLRS LED Indicator
--> Connect to SE2435L (CTX: Transmit enable control input)
--> Serial connection with a 12 kΩ resistor and connect to the ground
Tantalum Cap
Paschalis M.
ESP8285


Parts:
C29, C30: 10pF; C_0603_1608Metric_Pad1.08x0.95mm_HandSolder
C31: 100nF; C_0603_1608Metric_Pad1.08x0.95mm_HandSolder
C32: 2.2uF; C_0603_1608Metric_Pad1.08x0.95mm_HandSolder
R22: 10K; R_0603_1608Metric_Pad0.98x0.95mm_HandSolder
R23: 2.2K; R_0603_1608Metric_Pad0.98x0.95mm_HandSolder
R24: 1.2K; R_0603_1608Metric_Pad0.98x0.95mm_HandSolder
U7: SE2431L-R; SE2431L_SKY

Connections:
+3.3V: U7.20 (CSD), U7.21 (CPS); also elsewhere on the board
/ESP8285/ANT_SEL: U7.16 (ANT_SEL); also elsewhere on the board
/ESP8285/CTX: R22.2, U7.24 (CTX); also elsewhere on the board
/SE2431L/ANT1: U7.15 (ANT1); also elsewhere on the board
/SE2431L/ANT2: U7.13 (ANT2); also elsewhere on the board
/SE2431L/BOUT: R23.2, R24.2, U7.23 (BOUT)
/SE2431L/TR: U7.6 (T/R); also elsewhere on the board
/SE2431L/VCC1: C30.1, C32.1, U7.22 (VCC1)
/SE2431L/VCC2: C29.1, C31.1, U7.19 (VCC2)
GND: C29.2, C30.2, C31.2, C32.2, R22.1, U7.9 (GND), U7.10 (GND), U7.11 (GND), U7.12 (GND), U7.14 (GND), U7.18 (GND), U7.25 (EPAD); also elsewhere on the board
unnamed: R24.1, U7.2 (B1)
unnamed: R23.1, U7.1 (B2)

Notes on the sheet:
Paschalis M.
SE2431L is an RF front-end module designed for the 2.4 GHz ISM band, offering an integrated Power Amplifier (PA), Low Noise Amplifier (LNA), and antenna diversity switch.



Board: 4 copper layers, 39.4 x 39.7 mm, 81 parts (37 on the bottom side), 59 nets.

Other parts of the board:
hole1, hole2, hole3, hole4: MountingHole_4mm

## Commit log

2024-12-22 Add .gitignore for KiCad PCB project to exclude temporary and exported files
2024-12-26 Added datasheets for components and sensors
2024-12-26 Added HMC5883L and QMC5883L to schematic
    [Version_1_M10Q_HMC5883L.kicad_pcb, Version_1_M10Q_HMC5883L.kicad_sch, Version_2_M10Q_QMC5883L.kicad_pcb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]
2025-01-01 Add SensorFCPlus setup with ExpressLRS 2.4GHz and version 3 M10Q LSM303AH configuration
    [Version_3_M10Q_LSM303AH.kicad_pcb, Version_3_M10Q_LSM303AH.kicad_sch]
2025-01-04 Add ExpressLRS 900MHz Version 3 with M10Q and LSM303AH support
    [Version_3_M10Q_LSM303AH.kicad_pcb, Version_3_M10Q_LSM303AH.kicad_sch]
2025-01-08 Remove outdated KiCad project files for ExpressLRS 2.4GHz across all versions.
    [Version_1_M10Q_HMC5883L.kicad_pcb, Version_1_M10Q_HMC5883L.kicad_sch, Version_2_M10Q_QMC5883L.kicad_pcb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]
2025-01-08 Remove outdated KiCad project files for ExpressLRS 900MHz across all versions.
    [Version_1_M10Q_HMC5883L.kicad_pcb, Version_1_M10Q_HMC5883L.kicad_sch, Version_2_M10Q_QMC5883L.kicad_pcb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]
2025-01-08 Update README with Transmission Modes Classification.
    [ESP8285.kicad_sch, SE2435L.kicad_sch, SX1276.kicad_sch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]
2025-01-10 Remove outdated KiCAD project files
    [Version_1_M10Q_HMC5883L.kicad_pcb, Version_1_M10Q_HMC5883L.kicad_sch, Version_2_M10Q_QMC5883L.kicad_pcb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]
2025-01-13 Added "Go Back to Main README" button at the bottom of "Transmission Modes Classification" README
2025-01-15 Update KiCad files for ExpressLRS modules
    - Modified:
    - 2.4GHz Version 3 (M10Q LSM303AH) project and schematic files
    - 900MHz Version 3 (M10Q LSM303AH) schematic files for ESP8285 and SE2435L
    - Added:
    - 2.4GHz Version 3 schematics: ESP8285, SE2431, SE2431L, SX1280
    [ESP8285.kicad_sch, SE2431.kicad_sch, SE2431L.kicad_sch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]
2025-01-20 Update KiCad schematic and project files for ExpressLRS 2.4GHz modules (Version 1 and 2) and add new components (ESP8285, SE2431L, SX1280)
    [ESP8285.kicad_sch, SE2431L.kicad_sch, SX1280.kicad_sch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]
2025-01-23 Update README for Version 3 M10Q LSM303AH board
2025-01-23 Add image folder for Antenna Diversity Version 3 M10Q LSM303AH
2025-01-23 Track large files using Git LFS
2025-01-23 Add Board Designs Overview section and related Custom RX/TX Board Designs for GCS Communication project
2025-01-23 Update PCB design for Version 3 M10Q LSM303AH (ESP8285, SE2431L, SX1280, and main board)
    [ESP8285.kicad_sch, SE2431L.kicad_sch, SX1280.kicad_sch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]
2025-01-23 Updated README with board categories and PCB color information for better identification
2025-02-02 Update README.md and Version 2 files; add new GIF and MP4 for Version 2
    [ESP8285.kicad_sch, SE2431L.kicad_sch, SX1280.kicad_sch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]
2025-02-17 Updated README and V1 M10Q HMC5883L KiCad files, added documentation and media
    [ESP8285.kicad_sch, SE2431L.kicad_sch, SX1280.kicad_sch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]
2025-02-18 Updated Version_3_M10Q_LSM303AH
    [ESP8285.kicad_sch, SE2431L.kicad_sch, SX1280.kicad_sch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]
2025-02-18 Added PCB preview image and updated README
2025-02-23 Added datasheets for ExpressLRS communication module, ESP32-PICO-D4, and w3008 antenna
2025-03-05 Updated Version 1 files: schematics, project, README, and preview image
    [ESP8285.kicad_sch, SE2431L.kicad_sch, SX1280.kicad_sch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]
2025-03-16 Add True Diversity module and update README
    [ESP32.kicad_sch, RFX2401C_ANT1.kicad_sch, RFX2401C_ANT2.kicad_sch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]
2025-03-16 Update preview.png: Replace 'Under Construction' label with final schematic
